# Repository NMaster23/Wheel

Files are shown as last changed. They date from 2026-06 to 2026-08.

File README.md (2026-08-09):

# Wheel
An STM32F407VGT6 based microcontroller board designed for use with the OpenFFBoard firmware.
This is made to be used as a controller for a hoverboard hub motor. That way you can use the hoverboard for direct drive sim racing.

## Setup
This controller will be flashed with the OpenFFBoard firmware over the dedicated ST-Link port. It is the unlabeled 1 x 5 connector. I will then flash the hoverboard with: Hoverboard Firmware. This will then allow me to use the hoverboard as a regular BLDC motor thus allowing me to create a fully working sim wheel.

## BOM
This design requires a lot of parts. So there are 3 places the parts need to be bought from. Ebay for the motor itself, I am using a motherboard I already have that I have verified works with this.
Wheel V3 CSV: Wheel V3
Wheel Brake CSV: Wheel Brake

Motor: Hoverboard Wheel
PCB: JLCPCB
Miscellaneous Components: Amazon

### BOM Screenshots:
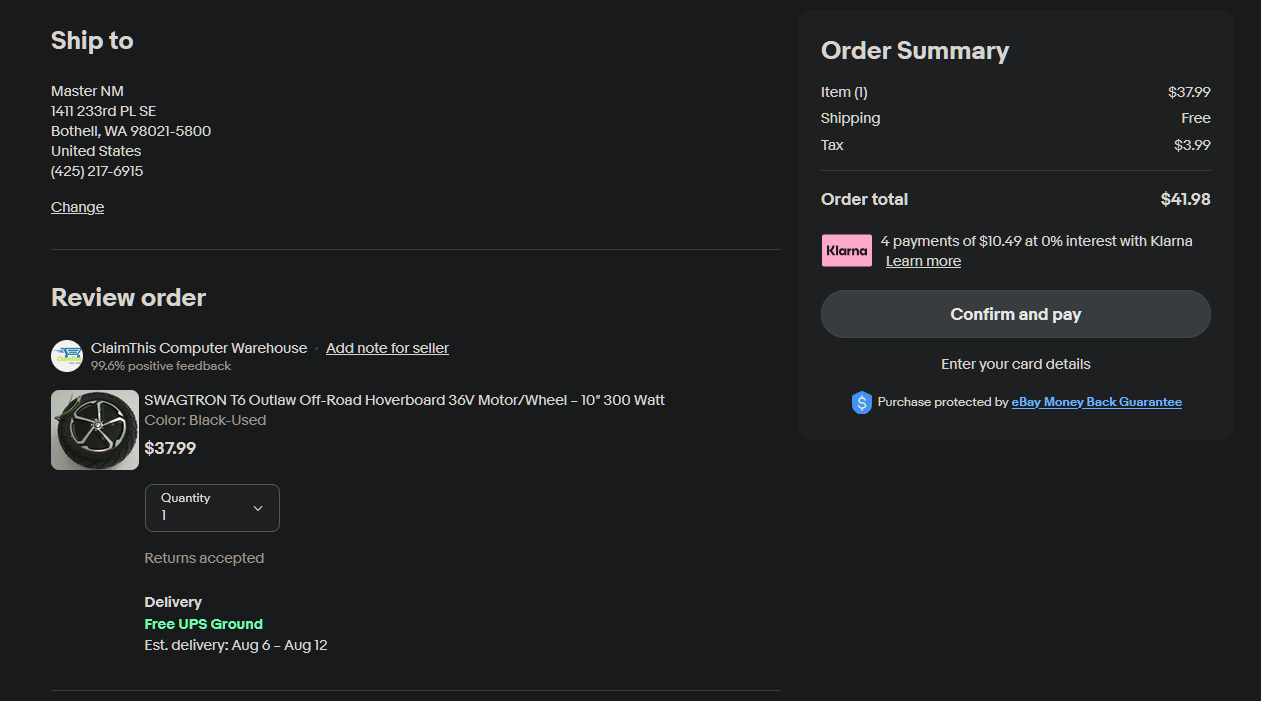
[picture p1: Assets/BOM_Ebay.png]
Ebay Checkout
Motor: 
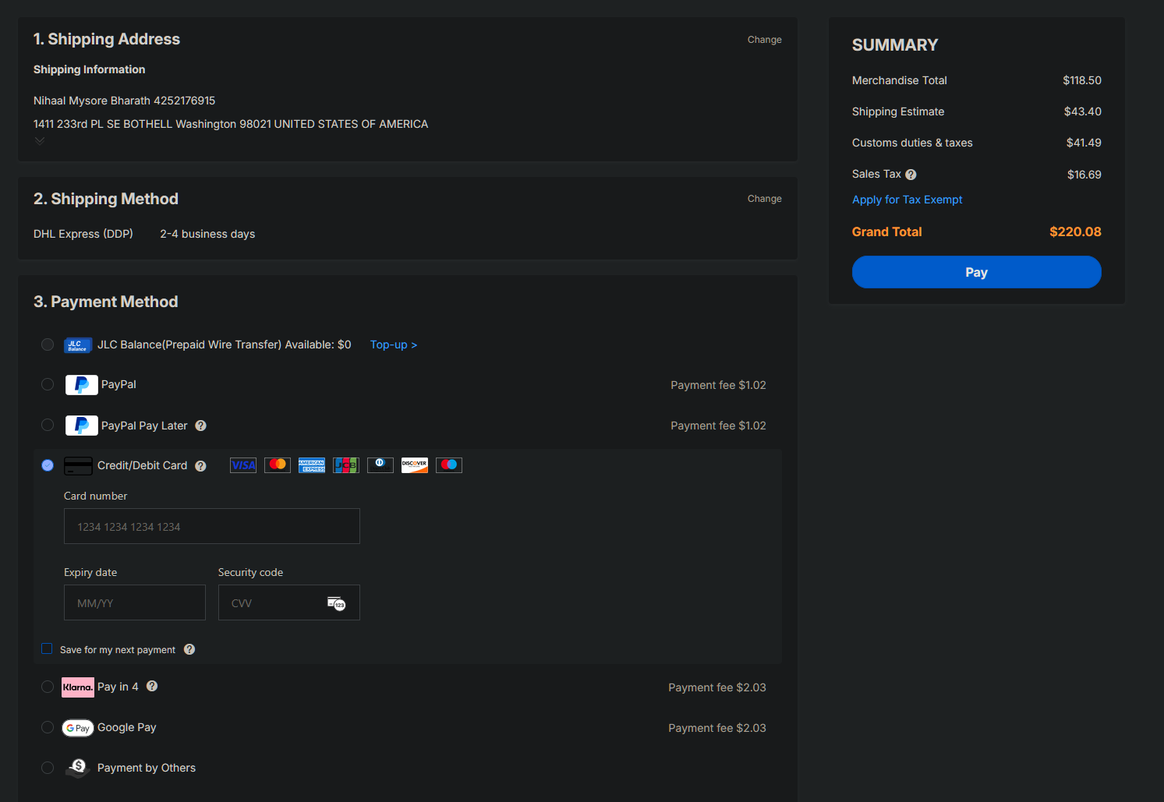
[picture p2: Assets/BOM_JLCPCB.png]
JLCPCB Checkout
PCB: 
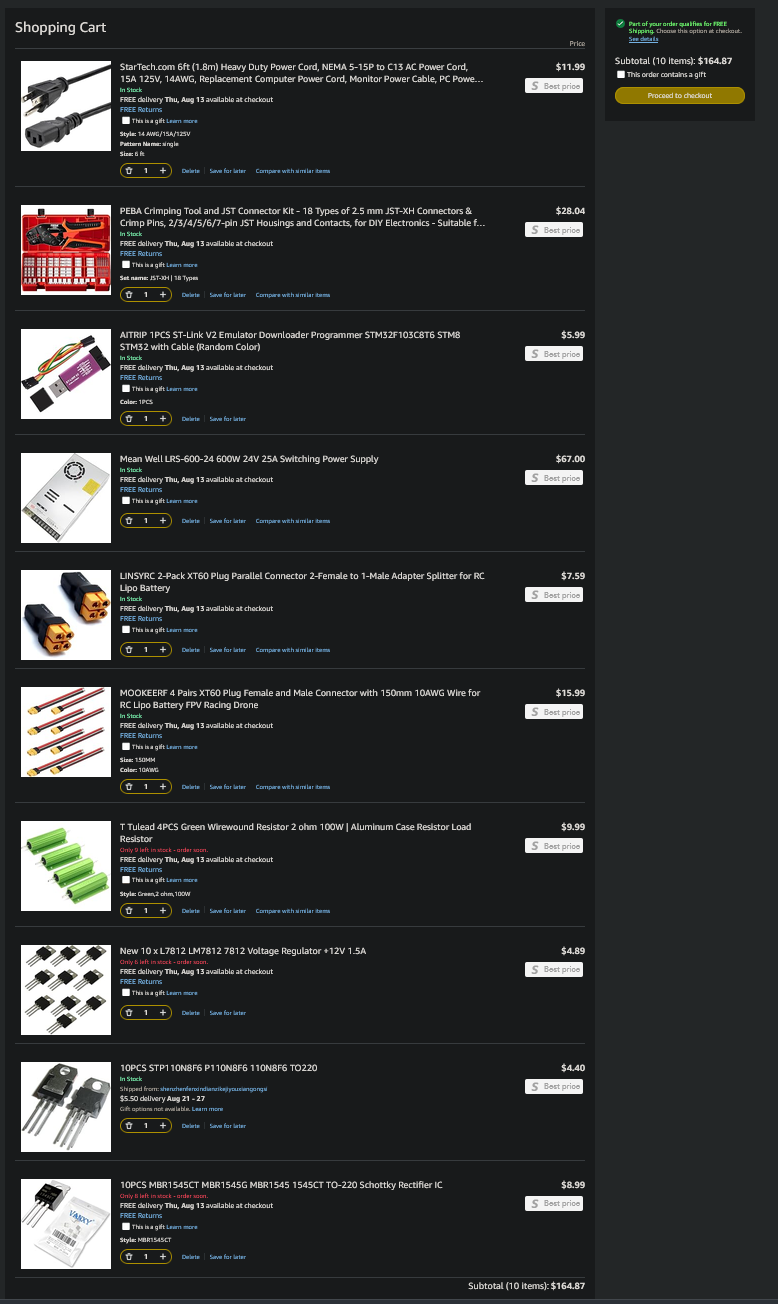
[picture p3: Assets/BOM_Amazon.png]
Amazon Cart
Miscellaneous Components: 

## Design

This is a picture of the full schematic:
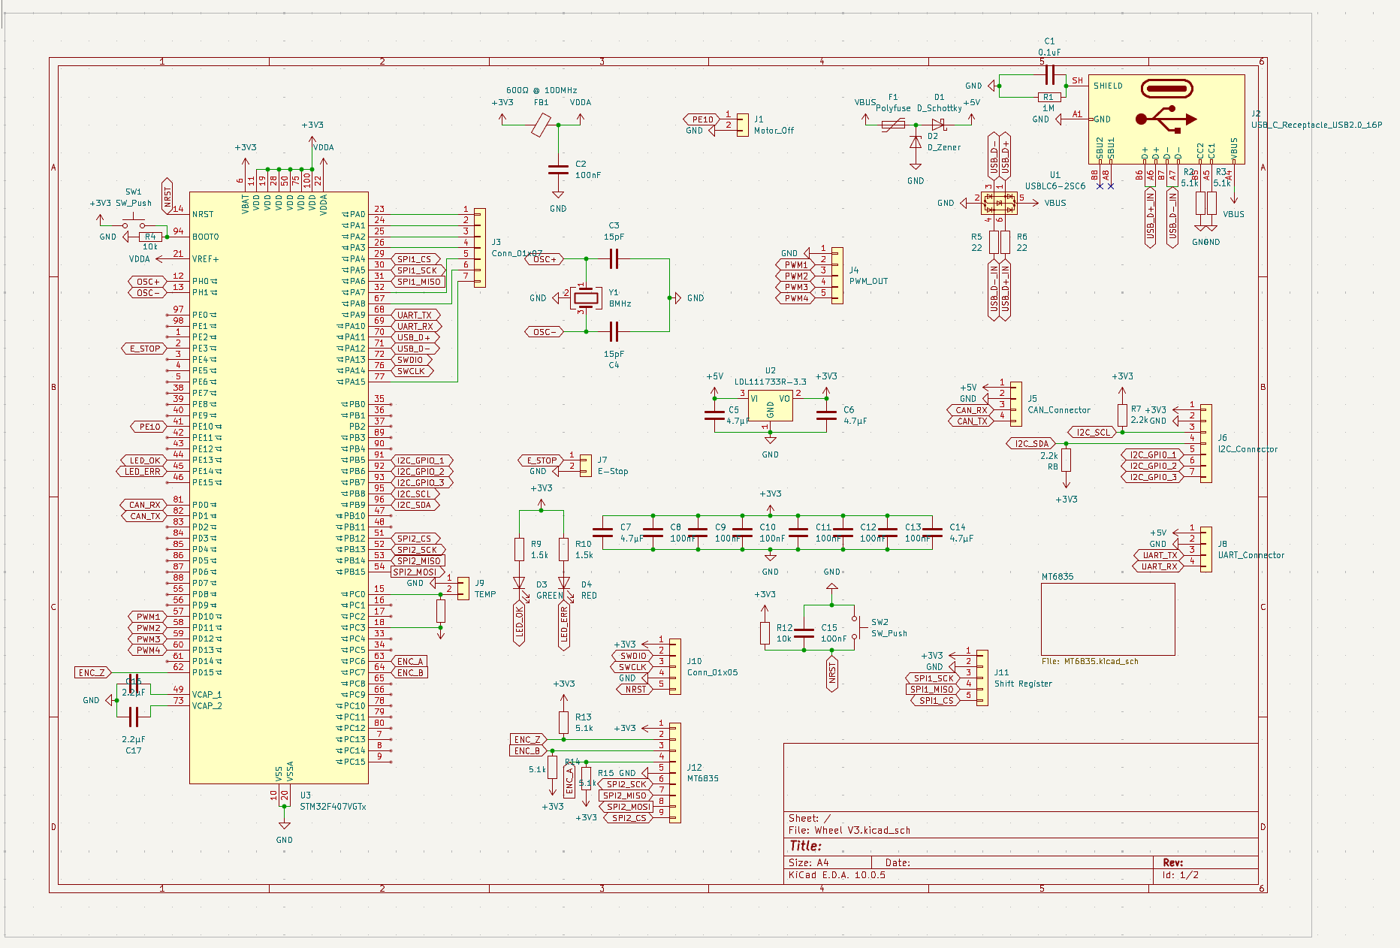
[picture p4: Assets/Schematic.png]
Schematic


This is a picture of the board for the MT6835 magnetic encoder:
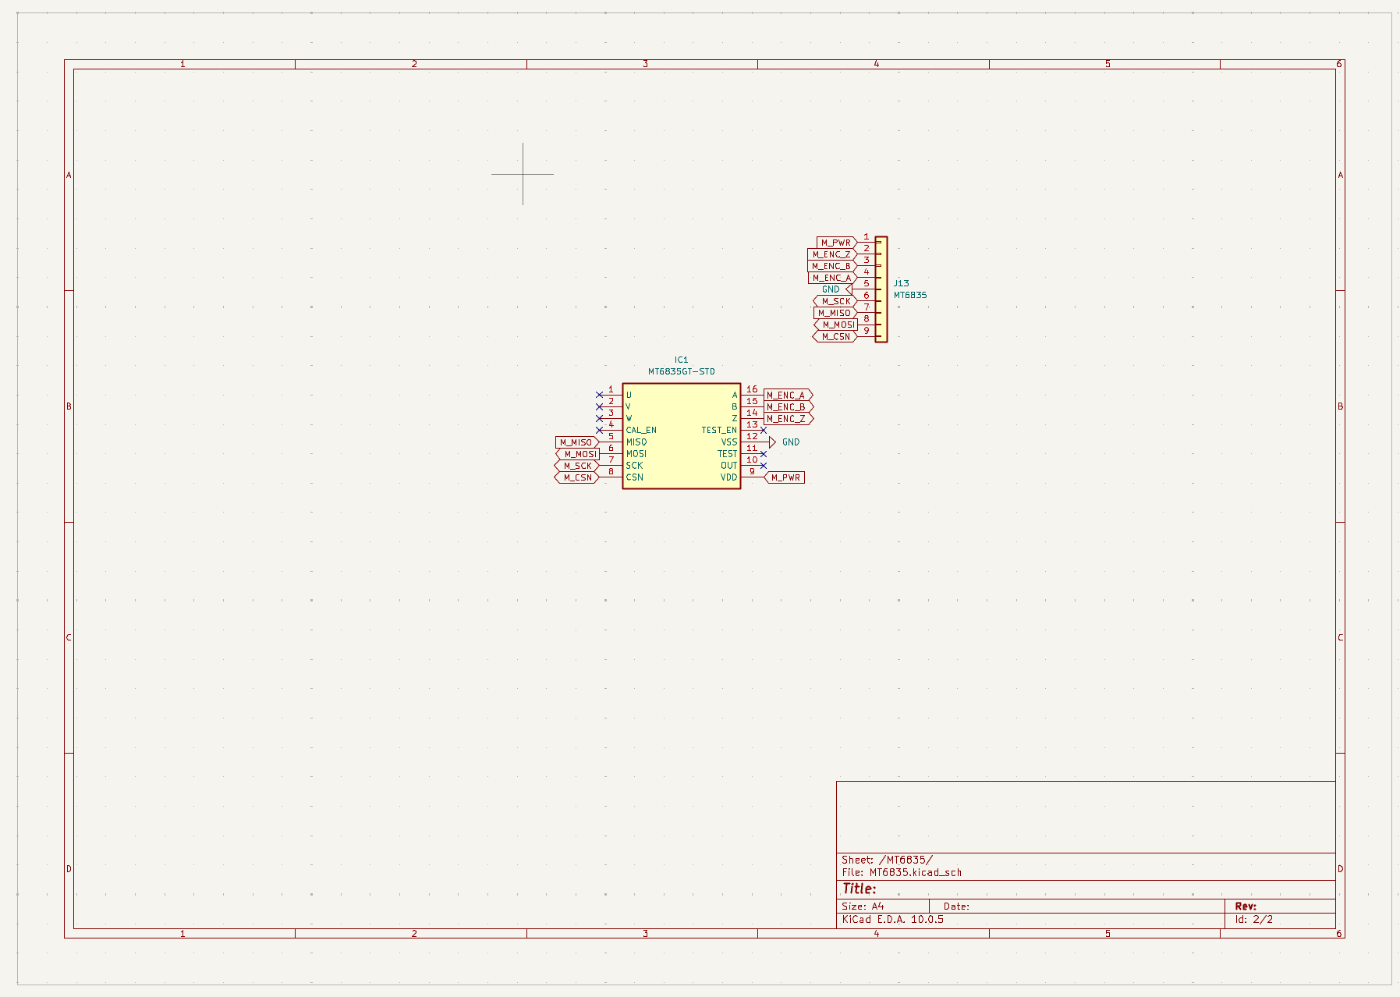
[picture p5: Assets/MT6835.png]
MT6835


This is a picture of the board for the Brake Chopper:
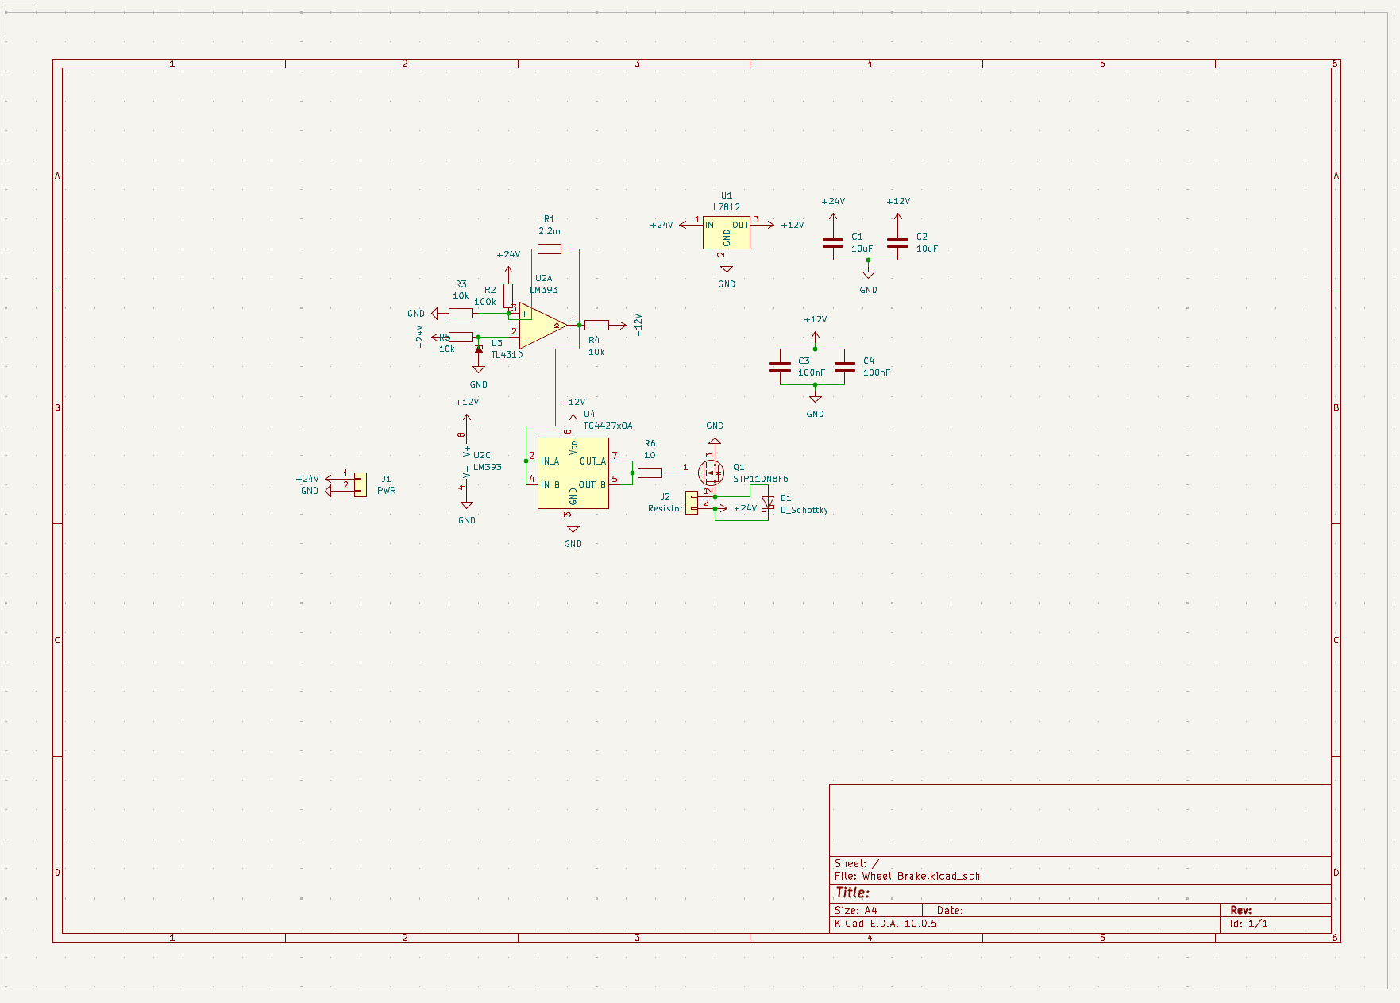
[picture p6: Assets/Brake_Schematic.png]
Brake Chopper


This is a picture of the full PCB:
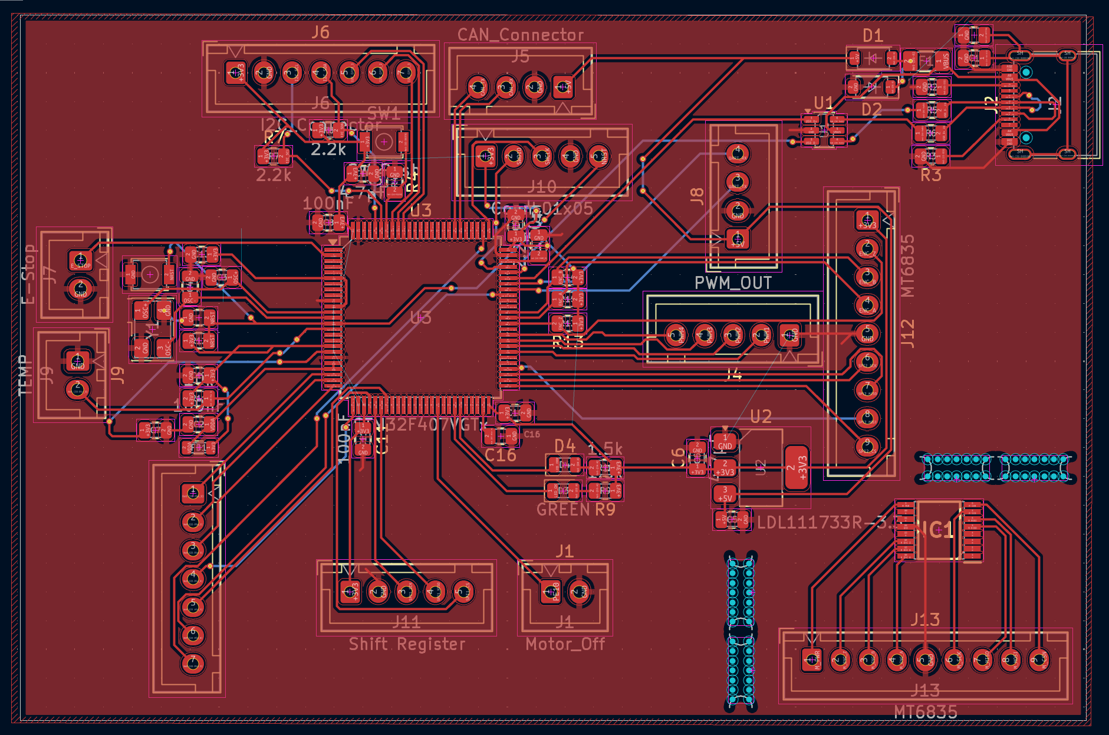
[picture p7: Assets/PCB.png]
PCB


This is a picture of the Brake Chopper PCB:
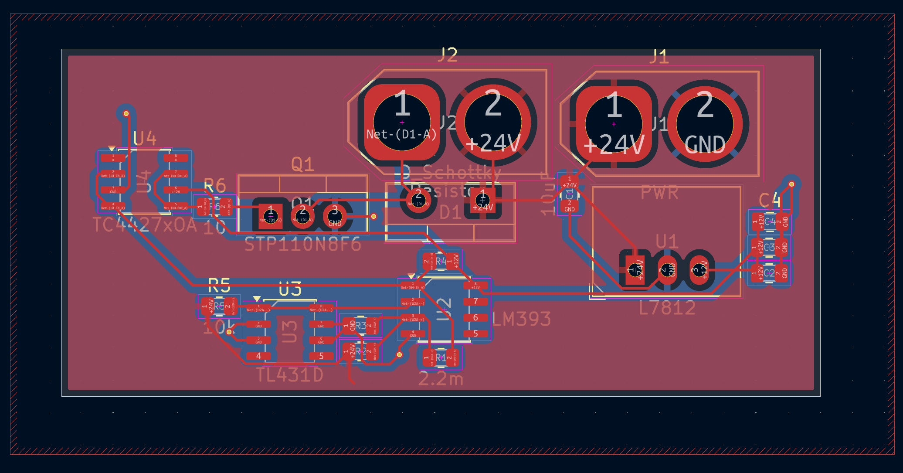
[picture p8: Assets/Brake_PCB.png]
Brake Chopper PCB


This is a picture of the expected product, but missing a few footprints:
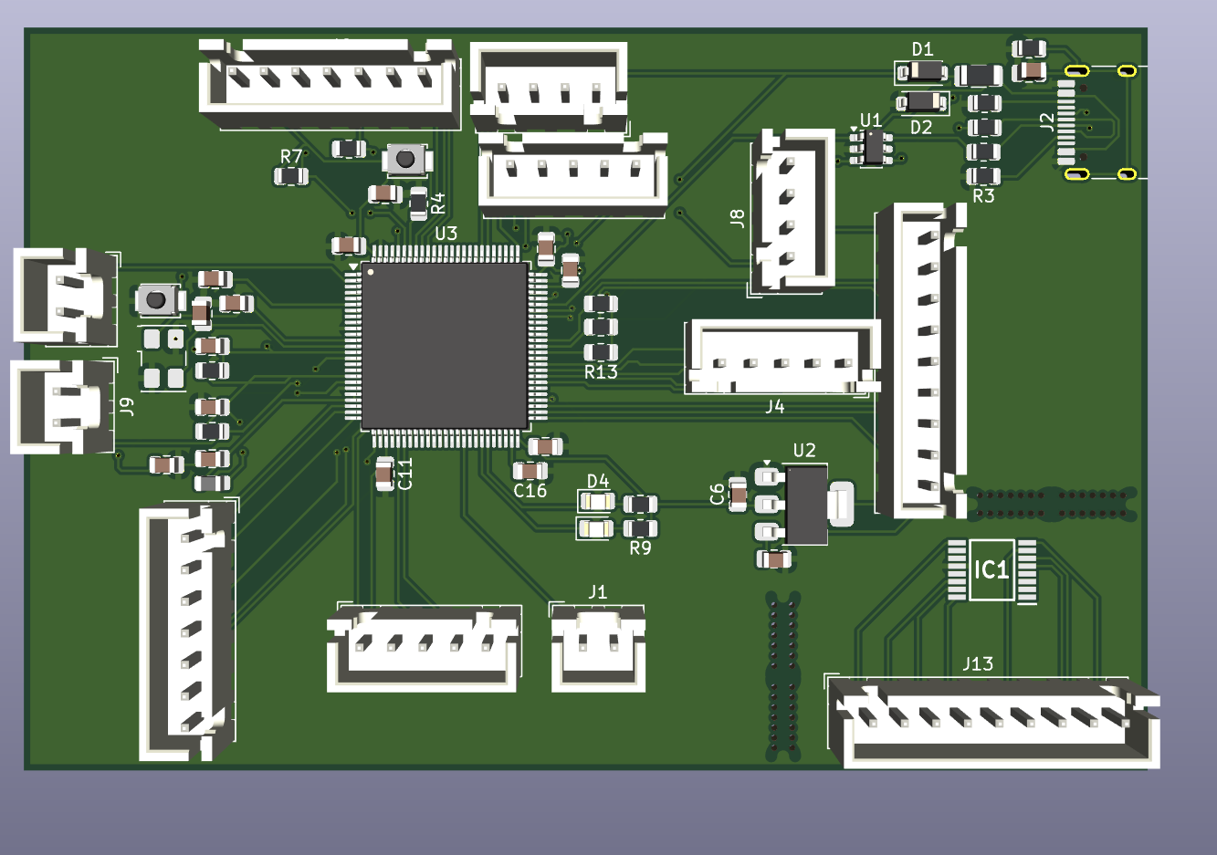
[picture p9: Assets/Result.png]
Product


This is a picture of the expected Brake Chopper:
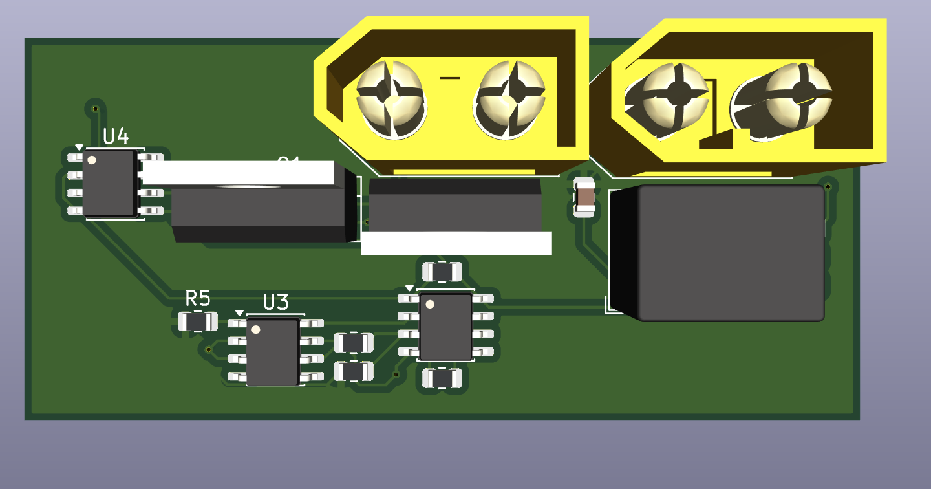
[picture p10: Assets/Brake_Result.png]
Expected Brake Chopper


## Why
I decided to try and make this project because ever since I was a kid I have always loved racing and playing racing games. I just could not afford to buy the actual wheel to play it on. And when one of my friends told me about Hack Club I got the opportunity to make what I want instead of just buying it off the shelf turning it into a learning experience. This has all come together for my wheel project with my hours of research and development coming together for this.

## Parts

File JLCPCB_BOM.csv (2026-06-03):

Designator | Comment | Footprint | LCSC Part Number
BT1 | Battery | BatteryHolder_Keystone_3002_1x2032
C1, C2, C3, C4, C5, C6, C7, C8, C13, C17, C18, C19 | 104 | C_0603_1608Metric
C9, C12, C14 | 106 | C_0805_2012Metric
C10, C11 | 2.2uF | C_0603_1608Metric
C15 | 4.7µF | C_0402_1005Metric
C16 | 0.1µF | C_0402_1005Metric
C20, C21 | 20P | C_0603_1608Metric
D1 | BDFN2A051U | D_SOD-882D
D2 | LED | LED_0603_1608Metric
D3 | BAT54C | SOT-23
J1 | USB_C_Receptacle_USB2.0_14P | USB_C_Receptacle_HRO_TYPE-C-31-M-12
J2, J3 | Conn_01x05 | PinHeader_1x05_P2.54mm_Vertical
J4, J5 | Conn_01x06 | PinHeader_1x06_P2.54mm_Vertical
J6 | Conn_01x04 | FanPinHeader_1x04_P2.54mm_Vertical
J7 | UART | FanPinHeader_1x04_P2.54mm_Vertical
R1 | 10k | R_0603_1608Metric
R2, R3 | 5.1k | R_0603_1608Metric
R4 | 10K | R_0603_1608Metric
R5 | 510R | R_0603_1608Metric
SW1 | SW_Push | SW_SPST_FSMSM
U1 | STM32F407VGTx | LQFP-100_14x14mm_P0.5mm
U2 | AMS1117-3.3 | SOT-223-3_TabPin2
U3 | MT6835 | TSSOP-16_4.4x5mm_P0.65mm
U4 | W25Q16JVSS | SOIC-8_5.3x5.3mm_P1.27mm
Y1 | 8MHz | Crystal_SMD_5032-2Pin_5.0x3.2mm

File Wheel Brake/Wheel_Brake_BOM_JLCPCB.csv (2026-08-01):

Comment | Designator | Footprint | LCSC Part #
10uF | C1,C2 | C_0805_2012Metric | C15850
100nF | C3,C4 | C_0805_2012Metric | C49678
D_Schottky - NEEDS PART SELECTION | D1 | TO-220-2_Vertical | TBD
PWR (XT60 Male) | J1 | AMASS_XT60-M_1x02_P7.20mm_Vertical | C98733
Resistor Tap (XT60 Male) | J2 | AMASS_XT60-M_1x02_P7.20mm_Vertical | C98733
STP110N8F6 | Q1 | TO-220-3_Vertical | C81146
2.2mOhm Shunt - NEEDS SOURCING | R1 | R_0805_2012Metric | TBD
100k | R2 | R_0805_2012Metric | C17407
10k | R3,R4,R5 | R_0805_2012Metric | C17414
10 - VERIFY VALUE | R6 | R_0805_2012Metric | TBD
R-78E12-0.5 (DC/DC 24V->12V) - NOT STOCKED | U1 | Converter_DCDC_RECOM_R-78E-0.5_THT | TBD
LM393 | U2 | SOIC-8_3.9x4.9mm_P1.27mm | C136033
TL431ACDT | U3 | SOIC-8_3.9x4.9mm_P1.27mm | C6969
TC4427AEOA | U4 | SOIC-8_3.9x4.9mm_P1.27mm | C18690

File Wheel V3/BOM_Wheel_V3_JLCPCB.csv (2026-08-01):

Comment | Designator | Footprint | LCSC Part #
0.1uF | C1 | C_0805_2012Metric | C49678
100nF | C2,C8,C9,C10,C11,C12,C13,C15 | C_0805_2012Metric | C49678
15pF | C3,C4 | C_0805_2012Metric | C107110
4.7uF | C5,C6,C7,C14 | C_0805_2012Metric | C98195
2.2uF | C16,C17 | C_0805_2012Metric | C19110
D_Schottky | D1 | D_SOD-123 | C130887
D_Zener | D2 | D_SOD-123 | C2827905
GREEN | D3 | LED_0805_2012Metric | C2297
RED | D4 | LED_0805_2012Metric | C2295
Polyfuse | F1 | Fuse_1206_3216Metric | C46641014
600ohm@100MHz | FB1 | L_0805_2012Metric | C85837
MT6835GT-STD | IC1 | SOP65P640X120-16N | C2932578
Motor_Off | J1 | JST_XH_B2B-XH-A_1x02_P2.50mm_Vertical | C158012
USB_C_Receptacle_USB2.0_16P | J2 | USB_C_Receptacle_HRO_TYPE-C-31-M-12 | C165948
Conn_01x07 | J3 | JST_XH_B7B-XH-A_1x07_P2.50mm_Vertical | C144398
PWM_OUT | J4 | JST_XH_B5B-XH-A_1x05_P2.50mm_Vertical | C157991
CAN_Connector | J5 | JST_XH_B4B-XH-A_1x04_P2.50mm_Vertical | C144395
I2C_Connector | J6 | JST_XH_B7B-XH-A_1x07_P2.50mm_Vertical | C144398
E-Stop | J7 | JST_XH_B2B-XH-A_1x02_P2.50mm_Vertical | C158012
UART_Connector | J8 | JST_XH_B4B-XH-A_1x04_P2.50mm_Vertical | C144395
TEMP | J9 | JST_XH_B2B-XH-A_1x02_P2.50mm_Vertical | C158012
Conn_01x05 | J10 | JST_XH_B5B-XH-A_1x05_P2.50mm_Vertical | C157991
Shift Register | J11 | JST_XH_B5B-XH-A_1x05_P2.50mm_Vertical | C157991
MT6835 | J12,J13 | JST_XH_B9B-XH-A_1x09_P2.50mm_Vertical | C157966
1M | R1 | R_0805_2012Metric | C17514
5.1k | R2,R3,R13,R14,R15 | R_0805_2012Metric | C27834
10k | R4,R11,R12 | R_0805_2012Metric | C17414
22 | R5,R6 | R_0805_2012Metric | C17561
2.2k | R7,R8 | R_0805_2012Metric | C17520
1.5k | R9,R10 | R_0805_2012Metric | C4310
SW_Push | SW1,SW2 | SW_SPST_B3U-1000P | C231329
USBLC6-2SC6 | U1 | SOT-23-6 | C2827654
LDL111733R-3.3 | U2 | SOT-223-3_TabPin2 | C435835
STM32F407VGTx | U3 | LQFP-100_14x14mm_P0.5mm | C12345
8MHz | Y1 | Crystal_SMD_5032-4Pin_5.0x3.2mm | C157341

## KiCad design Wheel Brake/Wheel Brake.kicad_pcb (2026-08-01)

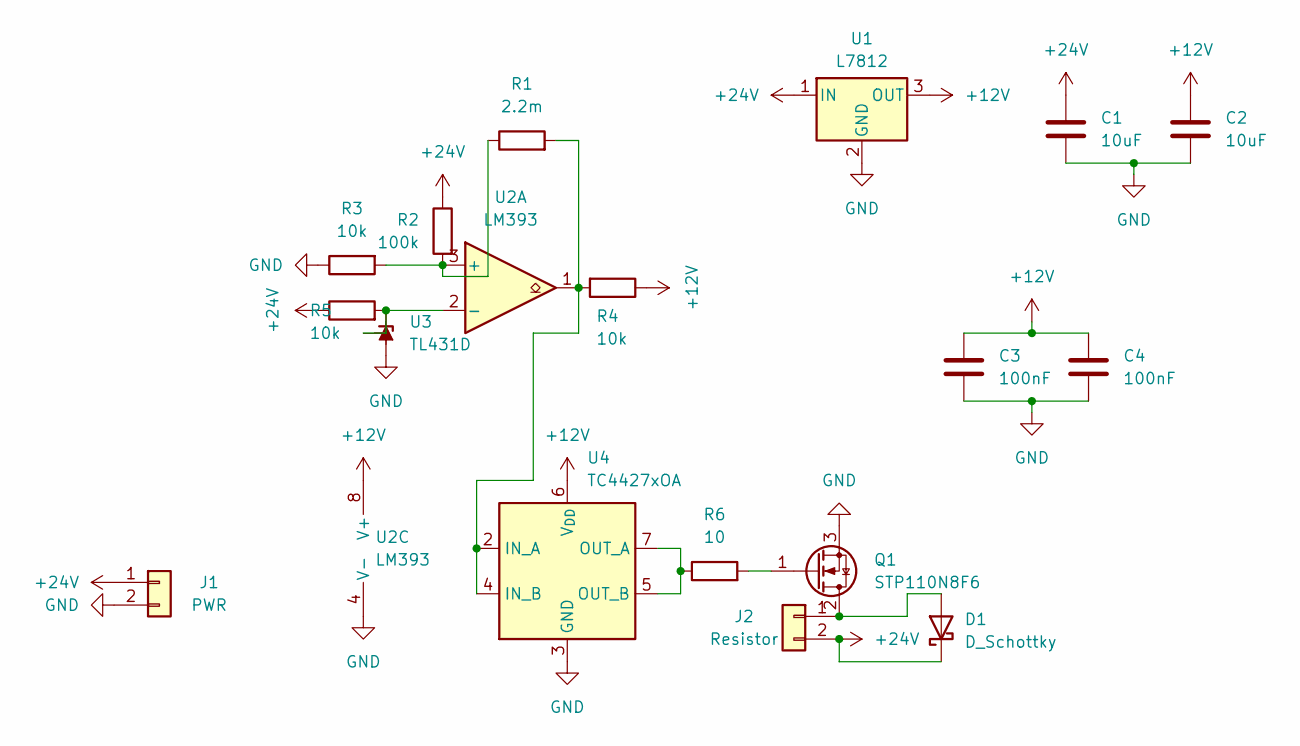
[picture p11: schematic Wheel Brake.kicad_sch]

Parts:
C1, C2: 10uF; C_0805_2012Metric
C3, C4: 100nF; C_0805_2012Metric
D1: D_Schottky; TO-220-2_Vertical
J1: PWR; AMASS_XT60-M_1x02_P7.20mm_Vertical
J2: Resistor; AMASS_XT60-M_1x02_P7.20mm_Vertical
Q1: STP110N8F6; TO-220-3_Vertical
R1: 2.2m; R_0805_2012Metric
R2: 100k; R_0805_2012Metric
R3, R4, R5: 10k; R_0805_2012Metric
R6: 10; R_0805_2012Metric
U1: L7812; Converter_DCDC_RECOM_R-78E-0.5_THT
U2: LM393; SOIC-8_3.9x4.9mm_P1.27mm
U3: TL431D; SOIC-8_3.9x4.9mm_P1.27mm
U4: TC4427xOA; SOIC-8_3.9x4.9mm_P1.27mm

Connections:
+12V: C2.1, C3.1, C4.1, R4.1, U1.3 (OUT), U2.8 (V+), U4.6 (V_{DD})
+24V: C1.1, D1.1 (K), J1.1, J2.2, R2.1, R5.1, U1.1 (IN)
GND: C1.2, C2.2, C3.2, C4.2, J1.2, Q1.3 (S), R3.1, U1.2 (GND), U2.4 (V-), U3.2 (A), U3.3 (A), U3.6 (A), U3.7 (A), U4.3 (GND)
unnamed: D1.2 (A), J2.1, Q1.2 (D)
unnamed: Q1.1 (G), R6.2
unnamed: R1.1, R2.2, R3.2, U2.3 (+)
unnamed: R5.2, U2.2 (-), U3.1 (K), U3.8 (REF)
unnamed: R1.2, R4.2, U2.1, U4.2 (IN_A), U4.4 (IN_B)
unnamed: R6.1, U4.5 (OUT_B), U4.7 (OUT_A)

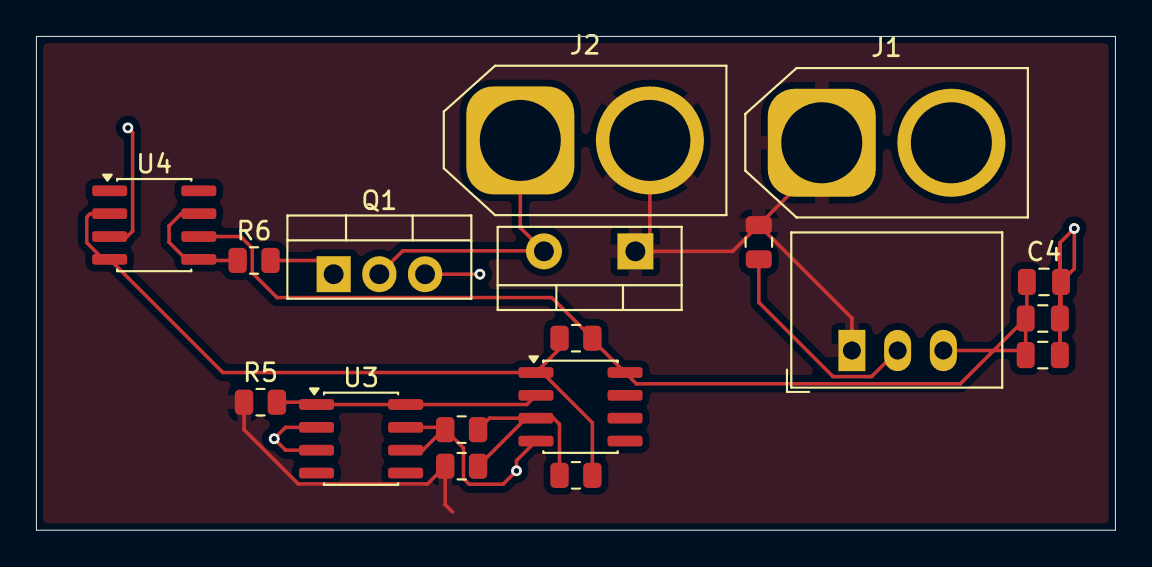
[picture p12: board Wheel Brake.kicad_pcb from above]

Board: 2 copper layers, 59.9 x 27.4 mm, 18 parts (0 on the bottom side), 9 nets.

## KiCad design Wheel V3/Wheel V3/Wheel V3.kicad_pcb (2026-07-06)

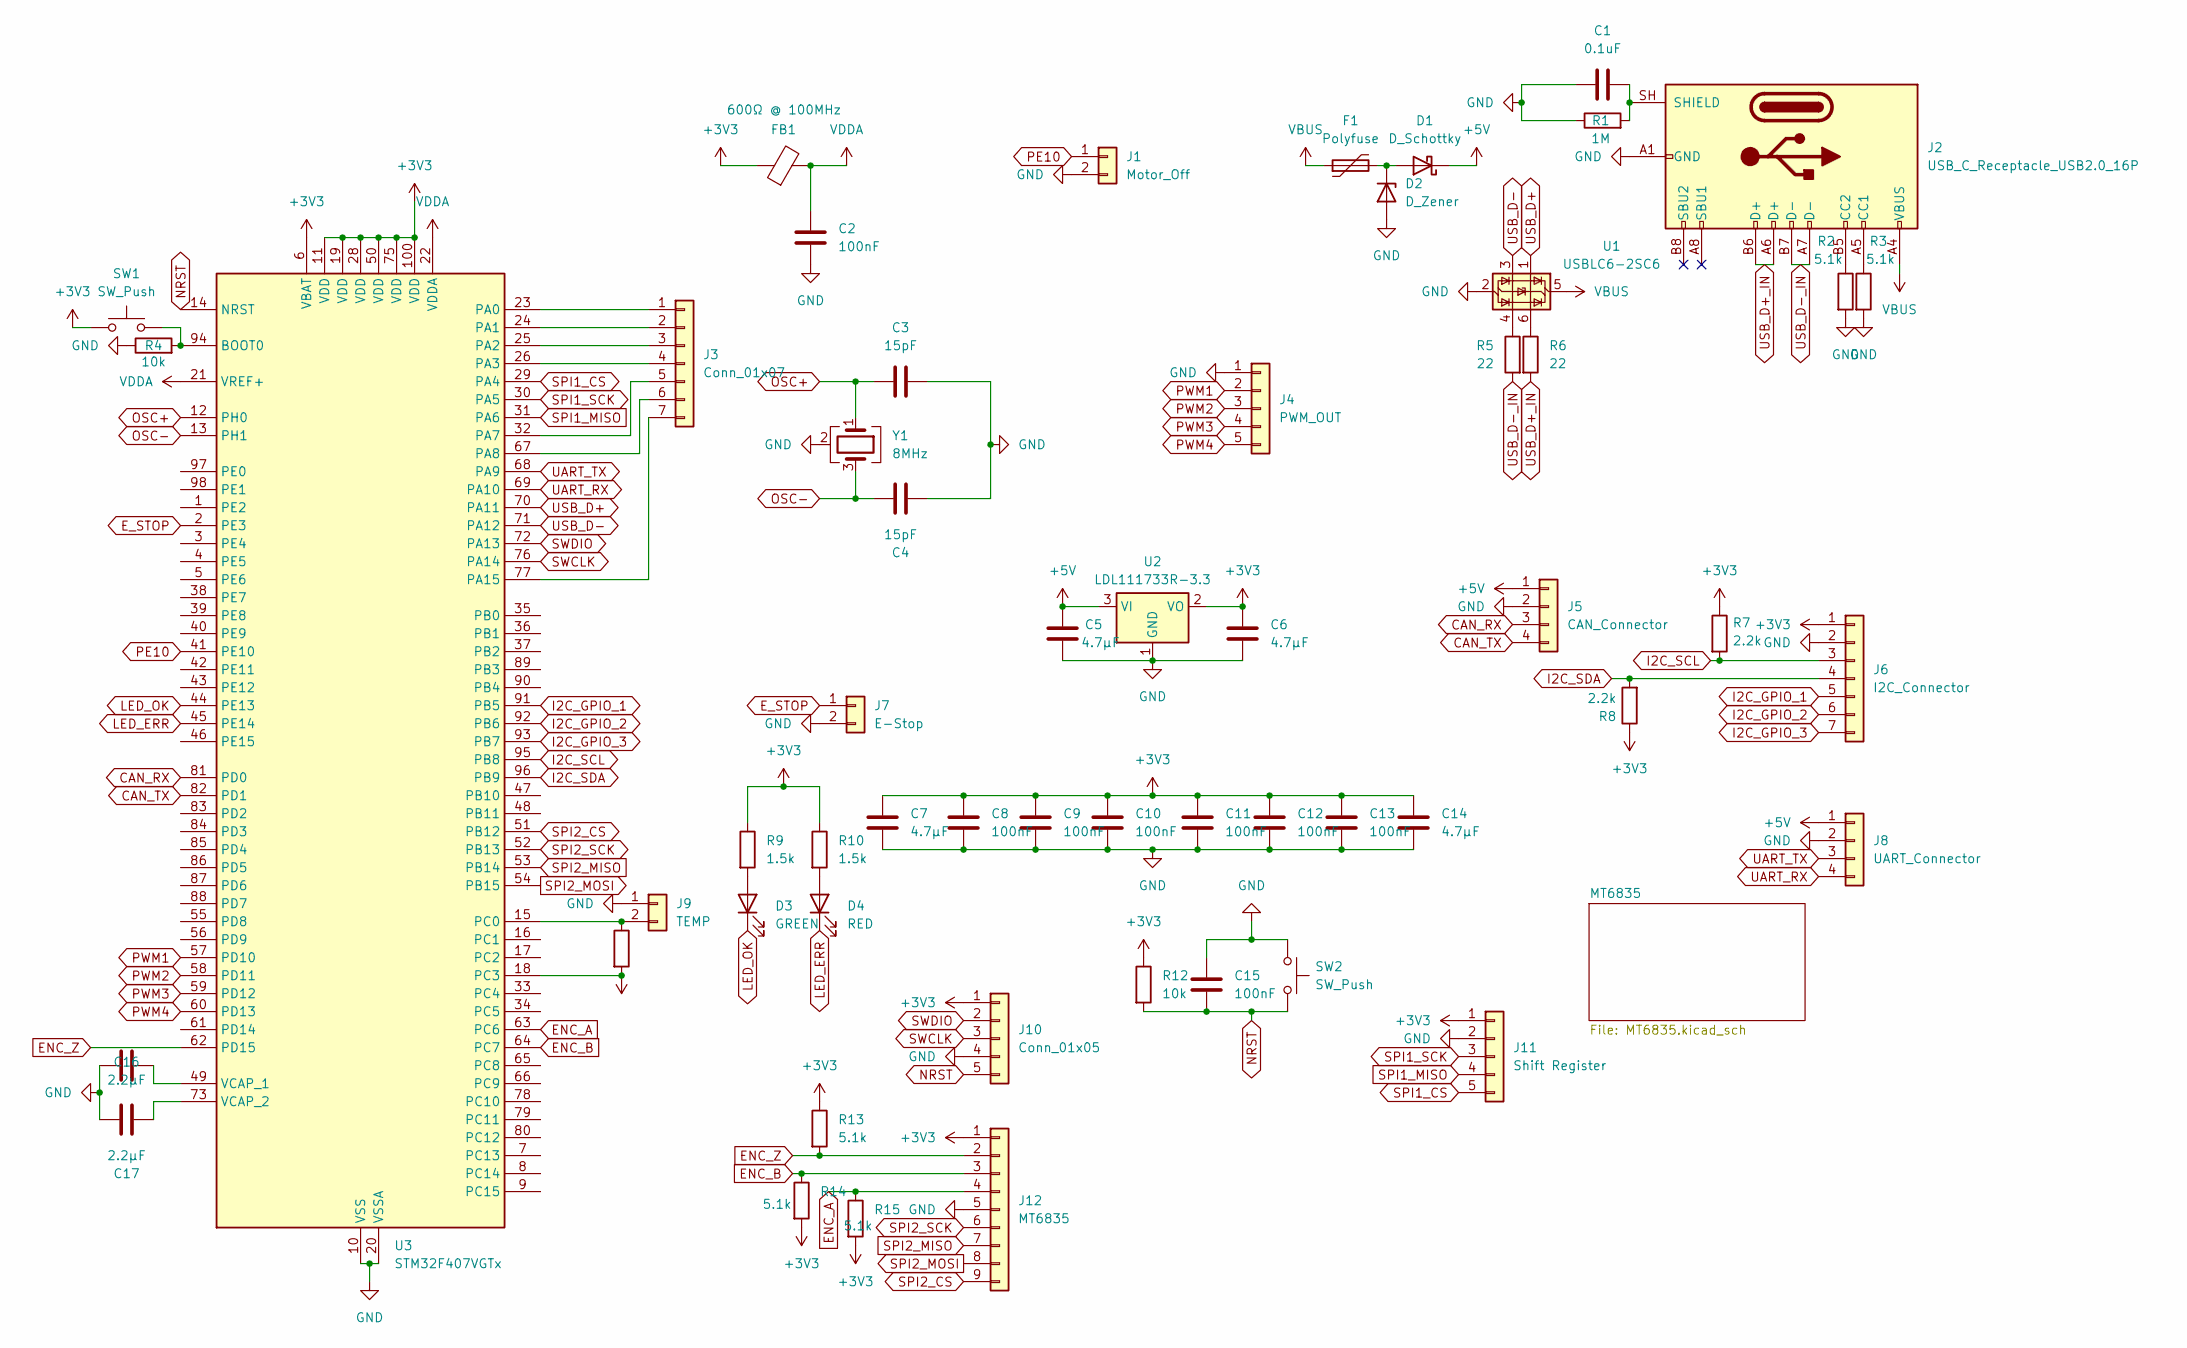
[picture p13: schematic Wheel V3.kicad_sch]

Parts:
C1: 0.1uF; C_0805_2012Metric
C2, C8, C9, C10, C11, C12, C13, C15: 100nF; C_0805_2012Metric
C3, C4: 15pF; C_0805_2012Metric
C5, C6, C7, C14: 4.7µF; C_0805_2012Metric
C16, C17: 2.2µF; C_0805_2012Metric
D1: D_Schottky; D_SOD-123
D2: D_Zener; D_SOD-123
D3: GREEN; LED_0805_2012Metric
D4: RED; LED_0805_2012Metric
F1: Polyfuse; Fuse_1206_3216Metric
FB1: 600Ω @ 100MHz; L_0805_2012Metric
J1: Motor_Off; JST_XH_B2B-XH-A_1x02_P2.50mm_Vertical
J2: USB_C_Receptacle_USB2.0_16P; USB_C_Receptacle_HRO_TYPE-C-31-M-12
J3: Conn_01x07; JST_XH_B7B-XH-A_1x07_P2.50mm_Vertical
J4: PWM_OUT; JST_XH_B5B-XH-A_1x05_P2.50mm_Vertical
J5: CAN_Connector; JST_XH_B4B-XH-A_1x04_P2.50mm_Vertical
J6: I2C_Connector; JST_XH_B7B-XH-A_1x07_P2.50mm_Vertical
J7: E-Stop; JST_XH_B2B-XH-A_1x02_P2.50mm_Vertical
J8: UART_Connector; JST_XH_B4B-XH-A_1x04_P2.50mm_Vertical
J9: TEMP; JST_XH_B2B-XH-A_1x02_P2.50mm_Vertical
J10: Conn_01x05; JST_XH_B5B-XH-A_1x05_P2.50mm_Vertical
J11: Shift Register; JST_XH_B5B-XH-A_1x05_P2.50mm_Vertical
J12: MT6835; JST_XH_B9B-XH-A_1x09_P2.50mm_Vertical
R1: 1M; R_0805_2012Metric
R2, R3, R13, R14, R15: 5.1k; R_0805_2012Metric
R4, R11, R12: 10k; R_0805_2012Metric
R5, R6: 22; R_0805_2012Metric
R7, R8: 2.2k; R_0805_2012Metric
R9, R10: 1.5k; R_0805_2012Metric
SW1, SW2: SW_Push; SW_SPST_B3U-1000P
U1: USBLC6-2SC6; SOT-23-6
U2: LDL111733R-3.3; SOT-223-3_TabPin2
U3: STM32F407VGTx; LQFP-100_14x14mm_P0.5mm
Y1: 8MHz; Crystal_SMD_5032-4Pin_5.0x3.2mm

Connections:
+3V3: C6.1, C7.1, C8.1, C9.1, C10.1, C11.1, C12.1, C13.1, C14.1, FB1.1, J6.1, J10.1, J11.1, J12.1, R7.1, R8.1, R9.1, R10.1, R11.2, R12.1, R13.1, R14.2, R15.2, SW1.1, U2.2 (VO), U3.6 (VBAT), U3.11 (VDD), U3.18 (PC3), U3.19 (VDD), U3.28 (VDD), U3.50 (VDD), U3.75 (VDD), U3.100 (VDD)
+5V: C5.1, D1.1 (K), J5.1, J8.1, U2.3 (VI)
CAN_RX: J5.3, U3.81 (PD0)
CAN_TX: J5.4, U3.82 (PD1)
ENC_A: J12.4, R15.1, U3.63 (PC6)
ENC_B: J12.3, R14.1, U3.64 (PC7)
ENC_Z: J12.2, R13.2, U3.62 (PD15)
E_STOP: J7.1, U3.2 (PE3)
GND: C1.2, C2.2, C3.2, C4.2, C5.2, C6.2, C7.2, C8.2, C9.2, C10.2, C11.2, C12.2, C13.2, C14.2, C15.1, C16.1, C17.1, D2.2 (A), J1.2, J2.A1 (GND), J2.A12 (GND), J2.B1 (GND), J2.B12 (GND), J4.1, J5.2, J6.2, J7.2, J8.2, J9.1, J10.4, J11.2, J12.5, R1.1, R2.2, R3.2, R4.1, SW2.1, U1.2 (GND), U2.1 (GND), U3.10 (VSS), U3.20 (VSSA), U3.27 (VSS), U3.74 (VSS), U3.99 (VSS), Y1.2 (G), Y1.4 (G); also elsewhere on the board
I2C_GPIO_1: J6.5, U3.91 (PB5)
I2C_GPIO_2: J6.6, U3.92 (PB6)
I2C_GPIO_3: J6.7, U3.93 (PB7)
I2C_SCL: J6.3, R7.2, U3.95 (PB8)
I2C_SDA: J6.4, R8.2, U3.96 (PB9)
LED_ERR: D4.1 (K), U3.45 (PE14)
LED_OK: D3.1 (K), U3.44 (PE13)
NRST: C15.2, J10.5, R12.2, SW2.2, U3.14 (NRST)
unnamed: D1.2 (A), D2.1 (K), F1.2
unnamed: D3.2 (A), R9.2
unnamed: D4.2 (A), R10.2
unnamed: J2.A5 (CC1), R3.1
unnamed: J2.B5 (CC2), R2.1
unnamed: C1.1, J2.SH (SHIELD), R1.2
unnamed: J3.1, U3.23 (PA0)
unnamed: J3.2, U3.24 (PA1)
unnamed: J3.3, U3.25 (PA2)
unnamed: J3.4, U3.26 (PA3)
unnamed: J3.5, U3.32 (PA7)
unnamed: J3.6, U3.67 (PA8)
unnamed: J3.7, U3.77 (PA15)
unnamed: J9.2, R11.1, U3.15 (PC0)
unnamed: R5.1, U1.4 (I/O2)
unnamed: R6.1, U1.6 (I/O1)
unnamed: R4.2, SW1.2, U3.94 (BOOT0)
unnamed: C16.2, U3.49 (VCAP_1)
unnamed: C17.2, U3.73 (VCAP_2)
OSC+: C3.1, U3.12 (PH0), Y1.1
OSC-: C4.1, U3.13 (PH1), Y1.3
PE10: J1.1, U3.41 (PE10)
PWM1: J4.2, U3.57 (PD10)
PWM2: J4.3, U3.58 (PD11)
PWM3: J4.4, U3.59 (PD12)
PWM4: J4.5, U3.60 (PD13)
SPI1_CS: J11.5, U3.29 (PA4)
SPI1_MISO: J11.4, U3.31 (PA6)
SPI1_SCK: J11.3, U3.30 (PA5)
SPI2_CS: J12.9, U3.51 (PB12)
SPI2_MISO: J12.7, U3.53 (PB14)
SPI2_MOSI: J12.8, U3.54 (PB15)
SPI2_SCK: J12.6, U3.52 (PB13)
SWCLK: J10.3, U3.76 (PA14)
SWDIO: J10.2, U3.72 (PA13)
UART_RX: J8.4, U3.69 (PA10)
UART_TX: J8.3, U3.68 (PA9)
USB_D+: U1.1 (I/O1), U3.70 (PA11)
USB_D+_IN: J2.A6 (D+), J2.B6 (D+), R6.2
USB_D-: U1.3 (I/O2), U3.71 (PA12)
USB_D-_IN: J2.A7 (D-), J2.B7 (D-), R5.2
VBUS: F1.1, J2.A4 (VBUS), J2.A9 (VBUS), J2.B4 (VBUS), J2.B9 (VBUS), U1.5 (VBUS)
VDDA: C2.1, FB1.2, U3.21 (VREF+), U3.22 (VDDA)

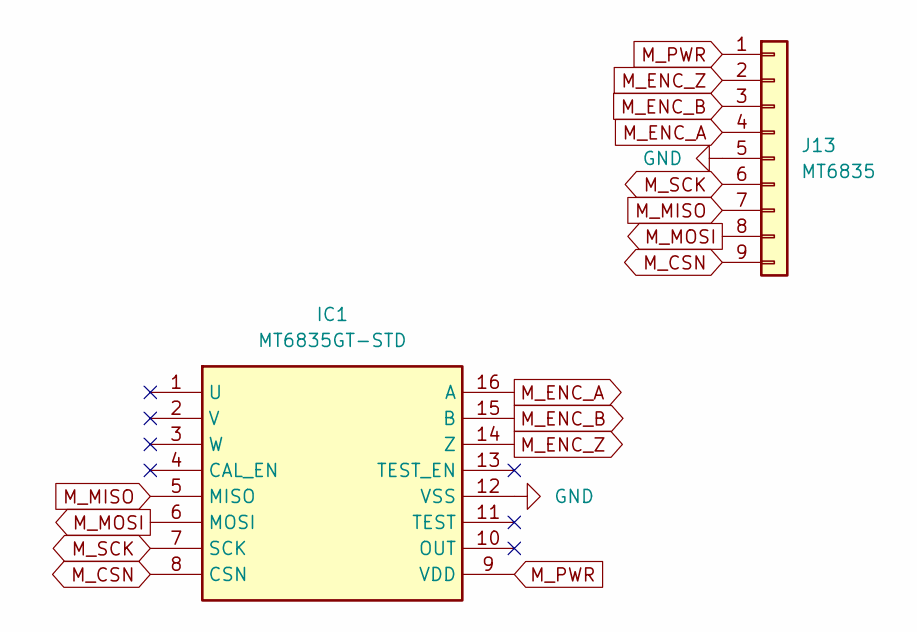
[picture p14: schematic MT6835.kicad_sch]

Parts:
IC1: MT6835GT-STD; SOP65P640X120-16N; Manufacturer_Part_Number MT6835GT-STD
J13: MT6835; JST_XH_B9B-XH-A_1x09_P2.50mm_Vertical

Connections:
GND: IC1.12 (VSS), J13.5; also elsewhere on the board
M_CSN: IC1.8 (CSN), J13.9
M_ENC_A: IC1.16 (A), J13.4
M_ENC_B: IC1.15 (B), J13.3
M_ENC_Z: IC1.14 (Z), J13.2
M_MISO: IC1.5 (MISO), J13.7
M_MOSI: IC1.6 (MOSI), J13.8
M_PWR: IC1.9 (VDD), J13.1
M_SCK: IC1.7 (SCK), J13.6

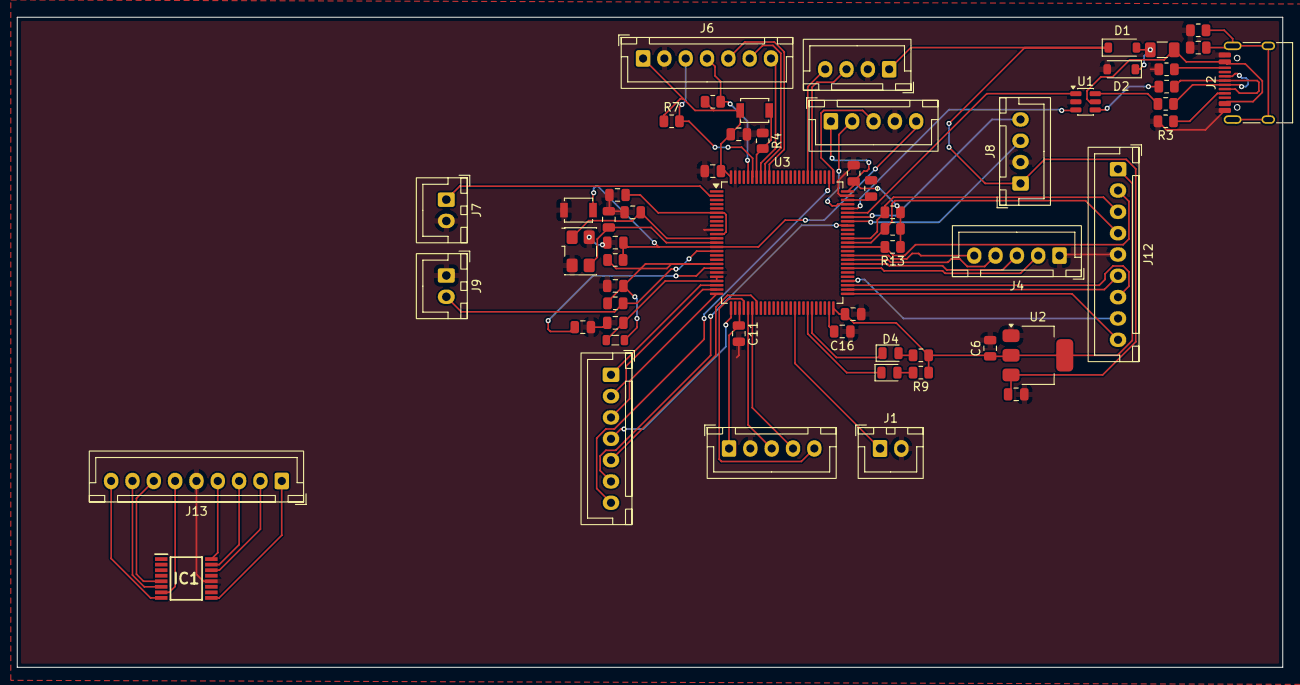
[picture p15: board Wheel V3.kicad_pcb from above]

Board: 2 copper layers, 148.3 x 76.2 mm, 58 parts (0 on the bottom side), 68 nets.

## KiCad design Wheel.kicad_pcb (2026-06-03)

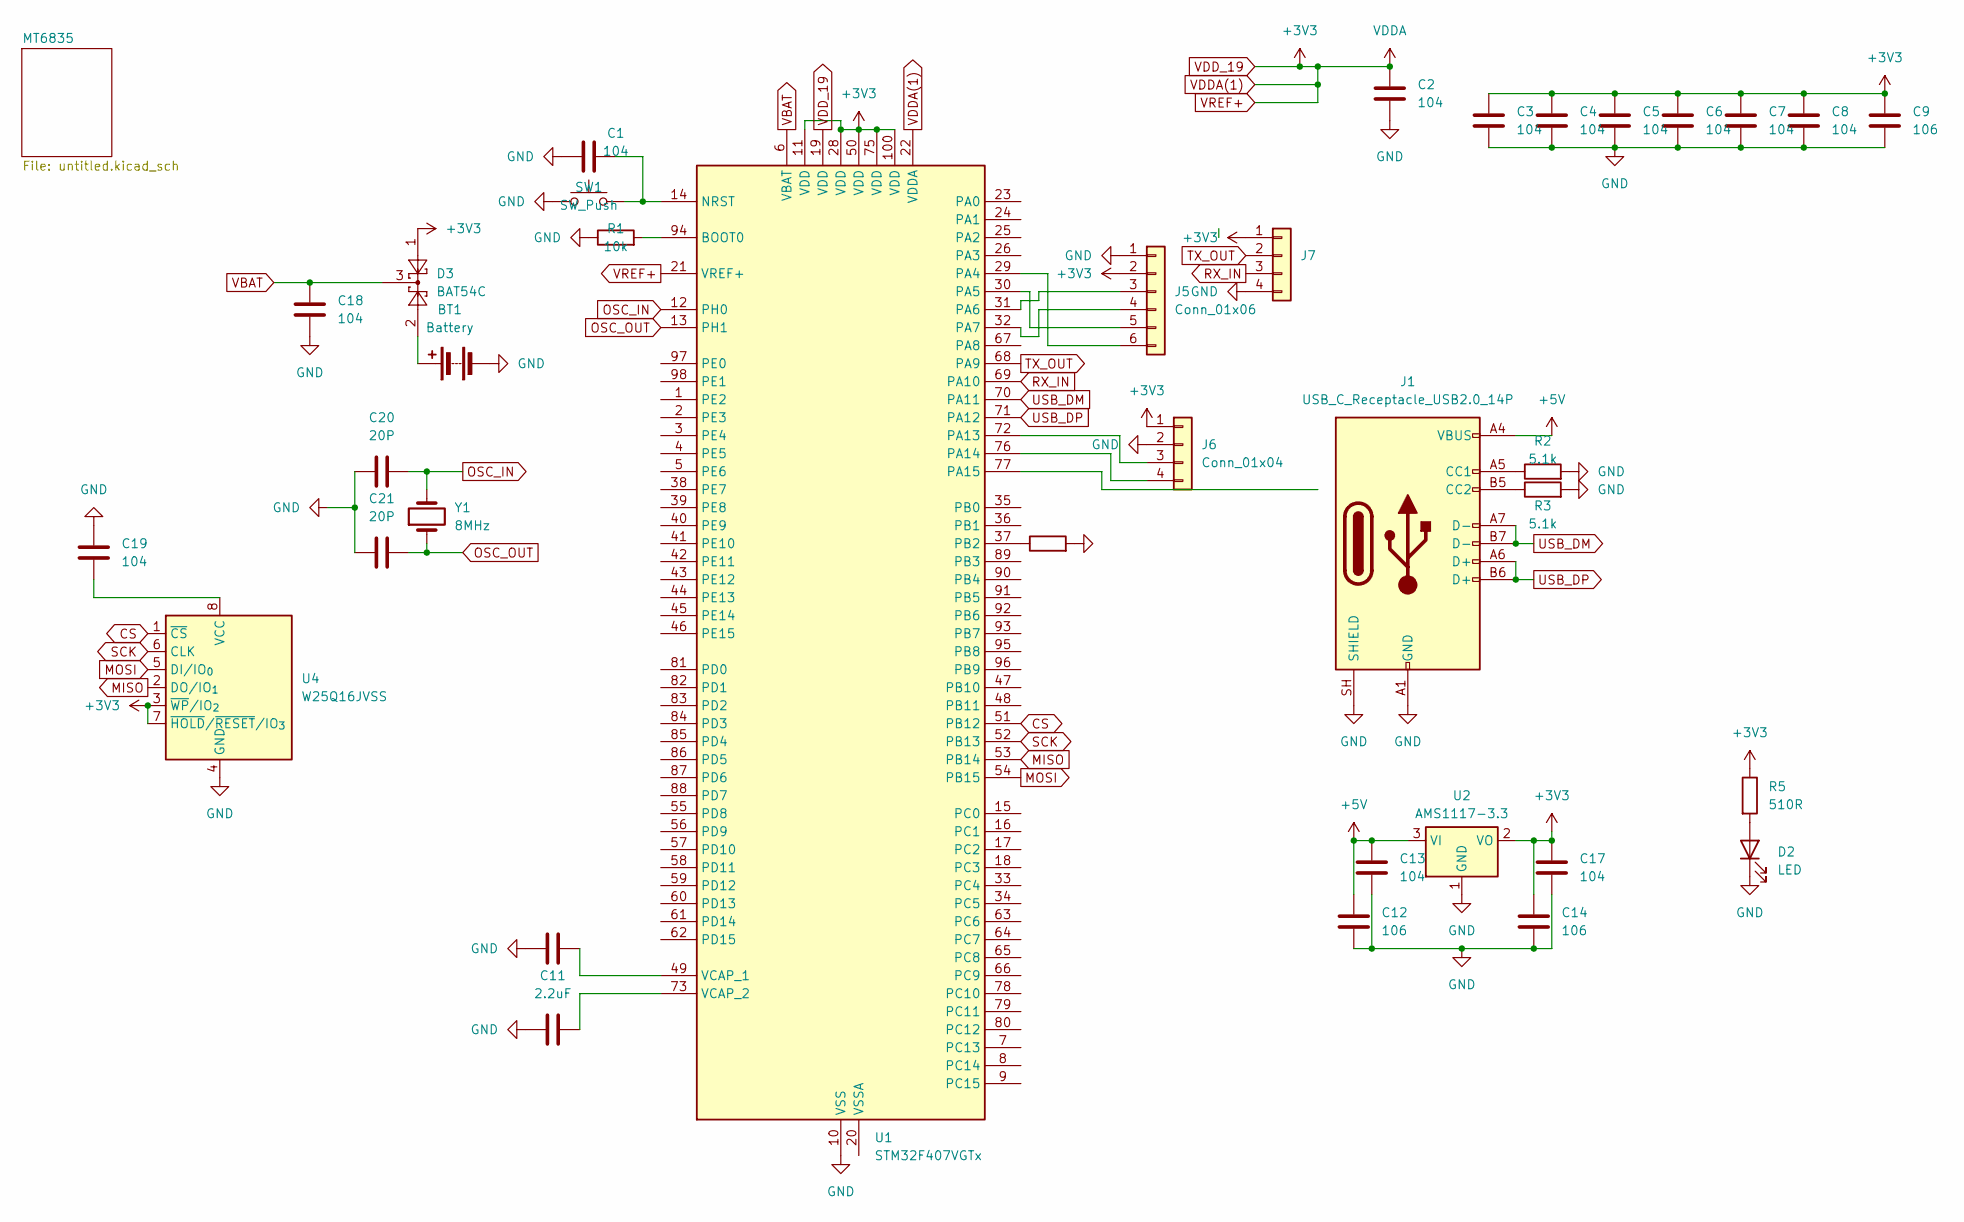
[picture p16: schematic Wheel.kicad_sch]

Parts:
BT1: Battery; BatteryHolder_Keystone_3002_1x2032
C1, C2, C3, C4, C5, C6, C7, C8, C13, C17, C18, C19: 104; C_0603_1608Metric
C9, C12, C14: 106; C_0805_2012Metric
C10, C11: 2.2uF; C_0603_1608Metric
C20, C21: 20P; C_0603_1608Metric
D2: LED; LED_0603_1608Metric
D3: BAT54C; SOT-23
J1: USB_C_Receptacle_USB2.0_14P; USB_C_Receptacle_HRO_TYPE-C-31-M-12
J5: Conn_01x06; PinHeader_1x06_P2.54mm_Vertical
J6: Conn_01x04; FanPinHeader_1x04_P2.54mm_Vertical
J7: UART; FanPinHeader_1x04_P2.54mm_Vertical
R1: 10k; R_0603_1608Metric
R2, R3: 5.1k; R_0603_1608Metric
R4: 10K; R_0603_1608Metric
R5: 510R; R_0603_1608Metric
SW1: SW_Push; SW_SPST_FSMSM
U1: STM32F407VGTx; LQFP-100_14x14mm_P0.5mm
U2: AMS1117-3.3; SOT-223-3_TabPin2
U4: W25Q16JVSS; SOIC-8_5.3x5.3mm_P1.27mm
Y1: 8MHz; Crystal_SMD_5032-2Pin_5.0x3.2mm

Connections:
+5V: C12.1, C13.1, J1.A4 (VBUS), J1.A9 (VBUS), J1.B4 (VBUS), J1.B9 (VBUS), U2.3 (VI)
CS: U1.51 (PB12), U4.1 (~CS)
GND: BT1.2 (-), C1.1, C2.1, C3.2, C4.2, C5.2, C6.2, C7.2, C8.2, C9.2, C10.1, C11.1, C12.2, C13.2, C14.2, C17.2, C18.2, C19.1, C20.1, C21.1, D2.1 (K), J1.A1 (GND), J1.A12 (GND), J1.B1 (GND), J1.B12 (GND), J1.SH (SHIELD), J5.1, J6.2, J7.4, R1.1, R2.2, R3.2, R4.2, SW1.1, U1.10 (VSS), U1.27 (VSS), U1.74 (VSS), U1.99 (VSS), U2.1 (GND), U4.4 (GND); also elsewhere on the board
MISO: U1.53 (PB14), U4.2 (DO/IO_{1})
MOSI: U1.54 (PB15), U4.5 (DI/IO_{0})
unnamed: BT1.1 (+), D3.2
unnamed: D2.2 (A), R5.2
unnamed: J1.A5 (CC1), R2.1
unnamed: J1.B5 (CC2), R3.1
unnamed: J5.3, U1.31 (PA6)
unnamed: J5.4, U1.32 (PA7)
unnamed: J5.5, U1.30 (PA5)
unnamed: J5.6, U1.29 (PA4)
unnamed: J6.3, U1.72 (PA13)
unnamed: J6.4, U1.76 (PA14)
unnamed: R1.2, U1.94 (BOOT0)
unnamed: C1.2, SW1.2, U1.14 (NRST)
unnamed: R4.1, U1.37 (PB2)
unnamed: C10.2, U1.49 (VCAP_1)
unnamed: C11.2, U1.73 (VCAP_2)
unnamed: C19.2, U4.8 (VCC)
OSC_IN: C20.2, U1.12 (PH0), Y1.2
OSC_OUT: C21.2, U1.13 (PH1), Y1.1
RX_IN: J7.3, U1.69 (PA10)
SCK: U1.52 (PB13), U4.6 (CLK)
TX_OUT: J7.2, U1.68 (PA9)
USB_DM: J1.A7 (D-), J1.B7 (D-), U1.70 (PA11)
USB_DP: J1.A6 (D+), J1.B6 (D+), U1.71 (PA12)
VBAT: C18.1, D3.3, U1.6 (VBAT)
VDDA(1): C2.2, C3.1, C4.1, C5.1, C6.1, C7.1, C8.1, C9.1, C14.1, C17.1, D3.1, J5.2, J6.1, J7.1, R5.1, U1.11 (VDD), U1.19 (VDD), U1.21 (VREF+), U1.22 (VDDA), U1.28 (VDD), U1.50 (VDD), U1.75 (VDD), U1.100 (VDD), U2.2 (VO), U4.3 (~WP/IO_{2}), U4.7 (~HOLD/~RESET/IO_{3}); also elsewhere on the board

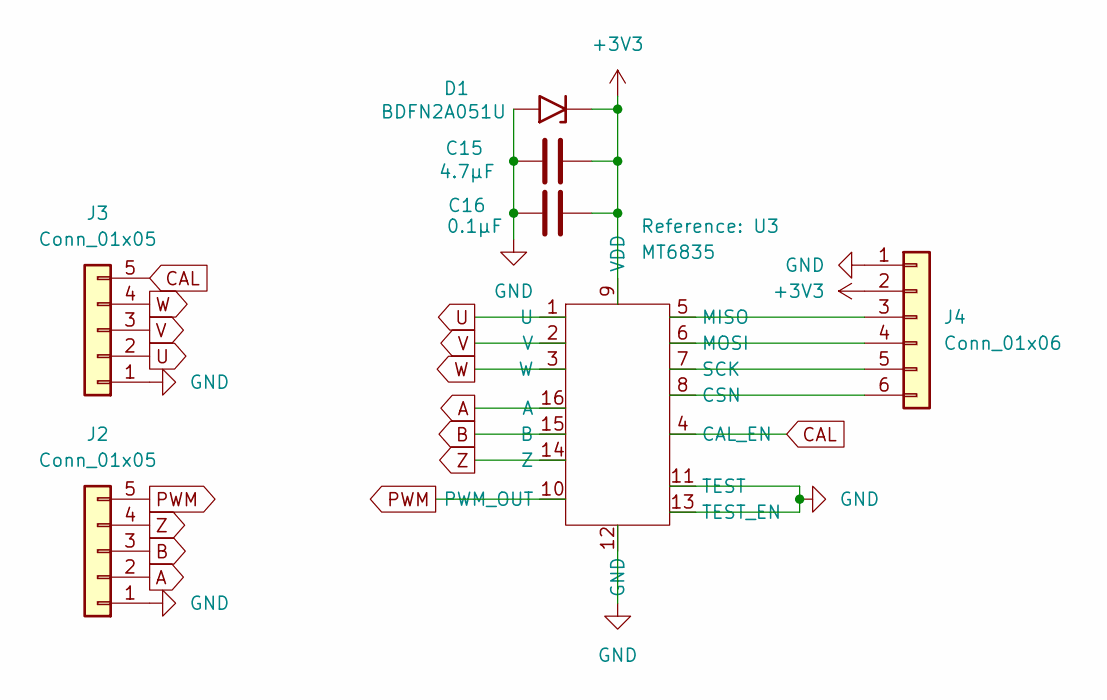
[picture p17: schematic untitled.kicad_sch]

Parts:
C15: 4.7µF; C_0402_1005Metric
C16: 0.1µF; C_0402_1005Metric
D1: BDFN2A051U; D_SOD-882D
J2, J3: Conn_01x05; PinHeader_1x05_P2.54mm_Vertical
J4: Conn_01x06; PinHeader_1x06_P2.54mm_Vertical
U3: MT6835; TSSOP-16_4.4x5mm_P0.65mm

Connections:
A: J2.2, U3.16 (A)
B: J2.3, U3.15 (B)
CAL: J3.5, U3.4 (CAL_EN)
GND: C15.1, C16.1, D1.2 (A2), J2.1, J3.1, J4.1, U3.11 (TEST), U3.12 (GND), U3.13 (TEST_EN); also elsewhere on the board
unnamed: J4.3, U3.5 (MISO)
unnamed: J4.4, U3.6 (MOSI)
unnamed: J4.5, U3.7 (SCK)
unnamed: J4.6, U3.8 (CSN)
PWM: J2.5, U3.10 (PWM_OUT)
U: J3.2, U3.1 (U)
V: J3.3, U3.2 (V)
VDDA(1): C15.2, C16.2, D1.1 (A1), J4.2, U3.9 (VDD); also elsewhere on the board
W: J3.4, U3.3 (W)
Z: J2.4, U3.14 (Z)

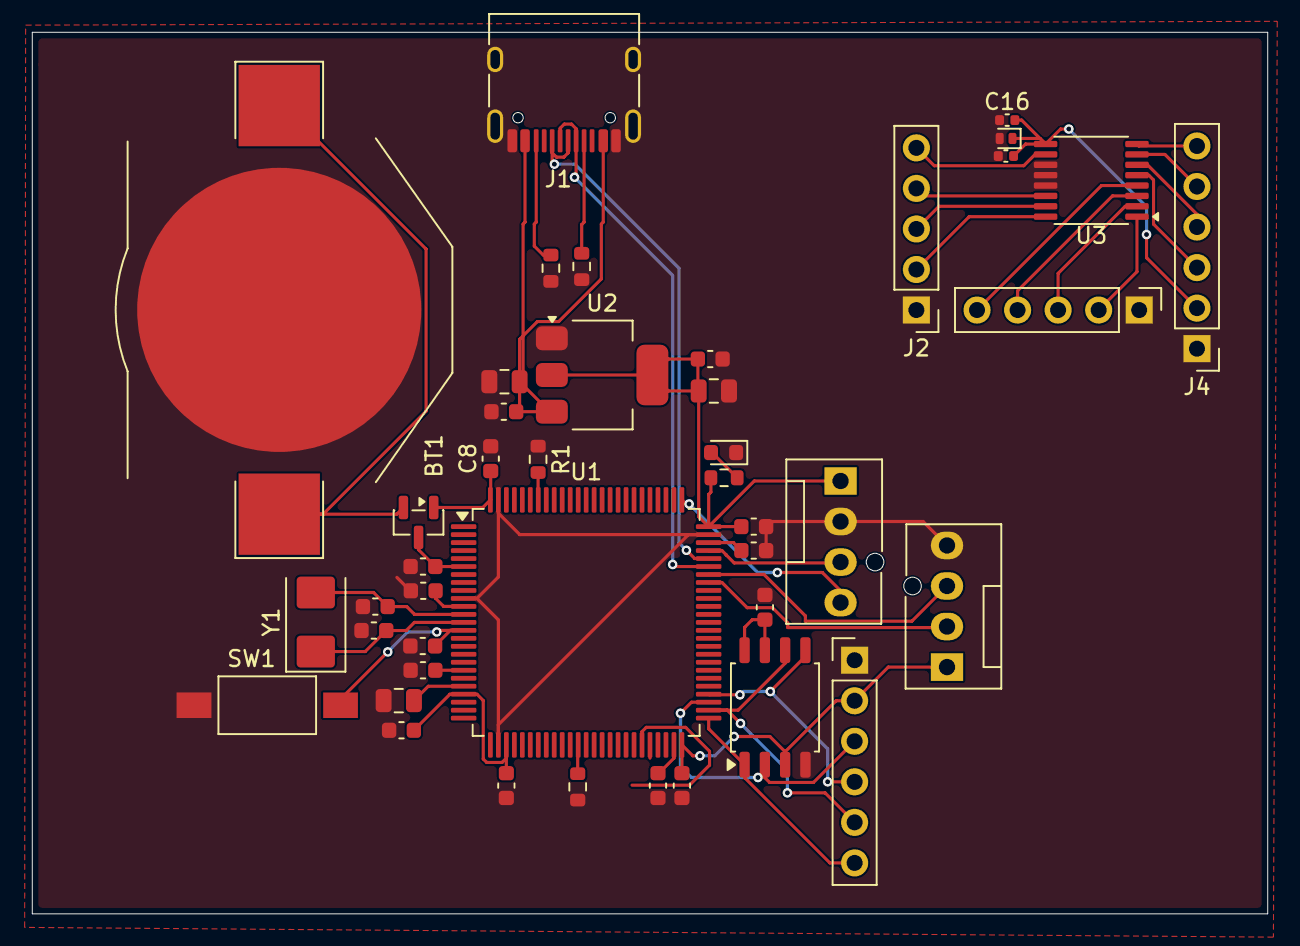
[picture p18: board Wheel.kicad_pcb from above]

Board: 2 copper layers, 77.4 x 55.2 mm, 43 parts (0 on the bottom side), 42 nets.

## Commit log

2026-05-15 Implemented Most of the Schematic
    [Wheel.kicad_sch]
2026-05-16 Finished Schematic
    [Wheel.kicad_sch, untitled.kicad_sch]
2026-05-26 Update README with images of project components
    Added images of schematic, board, PCB, and expected product.
2026-06-25 Decided to retry for the final time
    [JLCPCB_BOM.csv, Wheel V3.kicad_pcb, Wheel V3.kicad_sch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]
2026-08-01 Final Update
    [BOM_Wheel_V3_JLCPCB.csv, MT6835.kicad_sch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]
2026-08-07 Update README with BOM links and resources
    .
